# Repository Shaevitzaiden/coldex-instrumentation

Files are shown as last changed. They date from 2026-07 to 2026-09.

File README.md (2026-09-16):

# Pneumatic Control Dashboard

This revision keeps the fixed-grid dashboard and multi-device StreamHub
architecture while adding a central actuator registry shared by every
relay-driven control surface.

## Central actuator registry

`config/actuators.yaml` is the authoritative mapping from logical actuator IDs
to physical `device_id + relay_number` bindings. Pneumatic valve elements and
crusher controls store only `actuator_id`; the current physical binding is
resolved when a command is queued.

This prevents separate widgets from independently claiming the same relay and
means changing one actuator binding updates every command producer at once.
See `ACTUATOR_REGISTRY_GUIDE.md`.

## Device connectivity tile

`type: device_connectivity` provides a passive hardware-health table for every
device in `config/devices.yaml`. It reports role, connection state, configured
port/baud, latest telemetry age, observed frame rate, and detected sequence
gaps. It consumes existing `DataHub` messages and never opens or polls serial
ports itself. See `DEVICE_CONNECTIVITY_GUIDE.md`.

## Combined plot + numeric sensor tile

`type: sensor_plot_readout` combines a live one-axis plot with current-value
cards for multiple compatible sensors. Use `metadata.quantity` in
`config/sensors.yaml` to classify sensor channels. The Add Dashboard Panel
dialog exposes a Measurement Group selector and only permits sensors with the
same quantity and unit. See `SENSOR_PLOT_READOUT_GUIDE.md` and
`examples/sensor_plot_readout_dashboard_examples.yaml`.

## Generic numeric readout tile

`type: sensor_readout` displays arbitrary configured sensor values as live
numeric cards. Multiple readout tiles may coexist and may group mixed quantities
when that is useful for one subsystem. See `SENSOR_READOUT_GUIDE.md`.

## Crusher control tile

`type: crusher_control` adds four side-by-side Up/Down controls for relay-driven
pneumatic crushers. The tile references four logical actuator IDs from the
central registry, shares the existing controller DeviceManager worker, waits for
command results before confirming state, and can request startup retraction.
Relay uniqueness is enforced centrally by `ActuatorRegistry`, rather than by
widget-to-widget conflict checks. See `CRUSHER_CONTROL_GUIDE.md` and
`examples/crusher_control_dashboard_example.yaml`.

## Eight-column detachable dashboard

The default main window is now an 8-column by 3-row fixed grid:

- Pneumatic Valve Panel: 4 columns wide and 2 rows tall at upper left.
- Ice Crushers: 4 columns wide directly beneath the pneumatic panel.
- Live Sensor Plots: 2-column middle strip spanning the upper two rows.
- Sensor Values cards: 2-column middle strip on the bottom row.
- Session Recording: 2-column full-height right rail spanning all three rows.

The system log and device-connectivity tiles remain available, but are no longer
forced into the shipped main-window layout; they can be added into a free grid
location or spawned directly as floating windows.

Every dashboard tile can be opened as its own top-level window with the `↗`
button. Detached panels free their former grid cells for other widgets. The
window-manager **X** now closes/hides a floating panel instead of redocking it;
`↙` is the only redock action. Closed panels can be restored from **Dashboard →
Reopen Closed Panel…**. Saved layouts persist detached geometry and also persist
closed floating panels as `visible: false`.

For temporary or secondary panels, **Dashboard → Spawn Floating Panel…**
(`Ctrl+Shift+F`) creates the selected tile directly in a separate window, without
first placing it into the main grid. Multiple newly spawned windows are slightly
cascaded so they do not initially cover one another.

Session Recording has also been compacted for its narrow right rail: shortened
visible sensor labels, compact headers/path controls, and stretch behavior that
keeps the sensor-name column flexible while minimizing horizontal scrolling.

This custom mechanism deliberately keeps the stable fixed-grid dashboard instead
of using Qt's native dock splitter engine. See `DETACHABLE_DASHBOARD_GUIDE.md`.

### Recent usability changes

- Directly spawned floating panels no longer expand the main dashboard with a
  phantom bottom row. Empty docked rows collapse until a panel is redocked.
- The Ice Crushers panel has an always-visible **Configure Relay Bindings...**
  action for first-launch hardware setup. Bindings are validated globally and
  saved immediately to `config/actuators.yaml`.

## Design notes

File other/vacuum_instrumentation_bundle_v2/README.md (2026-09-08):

# Vacuum Instrumentation Integration Bundle v2

Reference code, wiring, and purchasing information for:
- Leybold GRAPHIX gauge controller via RS-232
- Granville-Phillips 475001-00-T via analog output
- MKS PDR-D-1 via analog DC output
- Adafruit Feather RP2040 Adalogger used directly as a low-cost four-channel USB analog DAQ

## What changed in v2
The external ADS1115 is now **optional**, not part of the baseline design. The Feather RP2040 Adalogger already exposes four onboard 12-bit ADC channels (A0-A3), which are adequate for these slow pressure-controller outputs when used with a resistor divider, RC filter, firmware averaging, and calibration.

The ADS1115 examples are retained as an upgrade path if later measurements need a more stable reference, better linearity/resolution, differential acquisition, or additional analog-performance margin.

## Recommended baseline hardware
One Feather RP2040 Adalogger acquires both analog instruments:
- A0 <- Granville-Phillips 475 analog output through 30.1k/10.0k divider
- A1 <- MKS PDR-D-1 DC OUT through 30.1k/10.0k divider
- A2/A3 <- spare 0-10 V channels

Each populated channel also gets 100 nF from the ADC node to signal ground.

The GRAPHIX remains a separate direct RS-232 connection to the laptop.

## Quick start
1. See `docs/WIRING.md` and build the native-ADC divider/filter front end.
2. Flash `firmware/adalogger_native_adc_arduino/adalogger_native_adc_arduino.ino` (recommended baseline). No ADS1115 library is needed.
3. Install Python dependencies: `pip install -r python/requirements.txt`.
4. Test GRAPHIX with `python/examples/graphix_smoketest.py`.
5. Set the DAQ COM port and PDR Baratron full-scale value in your application/example.
6. Calibrate the analog channels against a DMM if absolute voltage accuracy matters.

## BOM
- `bom/BOM.xlsx`: grouped, formatted BOM with separate sheets for the analog DAQ core, GP475, PDR-D-1, GRAPHIX RS-232, and optional upgrades.
- `bom/BOM.csv`: flat version with the same group labels and product URLs.

Prices are snapshots and will change. Cable lengths are installation dependent.

## Important configuration checks
- GRAPHIX: confirm RS-232 mode/baud and use a straight-through DB9 cable. Do not use TTL UART or a null-modem adapter/cable.
- GP475: confirm analog output is 1 V/decade, 0-7 V and preferably zero programmed offset.
- PDR-D-1: identify the attached Baratron and enter its actual full-scale range in software.
- Homemade DAQ: non-isolated. Check inter-instrument ground potential before tying signal grounds together.

## Firmware folders
- `firmware/adalogger_native_adc_arduino/` — recommended, no external ADC
- `firmware/adalogger_native_adc_circuitpython/` — same electrical design in CircuitPython
- `firmware/adalogger_ads1115_arduino/` — optional higher-performance ADC path
- `firmware/adalogger_ads1115_circuitpython/` — optional higher-performance ADC path

## Sources
See `docs/SOURCES.md` and the purchase URLs in the BOM.

## Scope
This is reference integration code, not a certified measurement or safety system. Confirm connector pinouts and instrument configuration against the exact hardware/manual before wiring.

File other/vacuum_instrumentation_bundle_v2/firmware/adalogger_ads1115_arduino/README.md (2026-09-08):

# Arduino firmware
Board: Adafruit Feather RP2040 Adalogger. Install the Adafruit RP2040 board package and **Adafruit ADS1X15** library. Connect the ADS1115 by STEMMA QT/Qwiic or SDA/SCL. Open the native USB serial port at 115200 baud.

Commands: `PING`, `INFO`, `READ`, `START`, `STOP`, `RATE <Hz>`. Output is newline-delimited JSON. `volts[]` are reconstructed **instrument-side** voltages using a 49.9k/10k divider.

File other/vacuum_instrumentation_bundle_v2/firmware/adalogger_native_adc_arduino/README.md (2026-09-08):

# Adalogger native-ADC firmware (recommended baseline)

This firmware uses the Feather RP2040 Adalogger's four onboard analog inputs A0-A3. No external ADC is required for the GP475 and PDR-D-1.

## Electrical front end per channel
- 30.1 kΩ ±0.1% from instrument output to ADC node
- 10.0 kΩ ±0.1% from ADC node to signal ground
- 100 nF X7R from ADC node to signal ground

The divider gain is 4.01, so 10 V at the instrument becomes about 2.494 V at the Feather. This leaves room for the GP475's ~10 V fault indication and prevents normal signals from approaching the 3.3 V ADC limit.

## Arduino setup
Select the Adafruit Feather RP2040 board/core as appropriate and upload `adalogger_native_adc_arduino.ino`. No extra ADC library is required.

## Calibration
The RP2040 ADC is adequate for these slow gauges but is not a precision metrology ADC. For better absolute voltage accuracy, apply at least a two-point calibration per channel using a reliable DMM and known input voltages. Edit `CAL_SCALE` and `CAL_OFFSET_V` in the sketch.

## USB commands
`PING`, `INFO`, `READ`, `START`, `STOP`, and `RATE <Hz>`.

The JSON sample format is intentionally identical to the ADS1115 firmware so the same Python host driver works with either implementation.

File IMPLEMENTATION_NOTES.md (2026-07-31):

# Implementation Notes — v6.8 Multi-Device Stream Hub

## Scope

The stable v6.7 fixed-grid GUI and valve editor were retained. The backend was refactored through migration phases 1–5:

1. source-qualified data models;
2. multiple independent device workers;
3. centralized thread-safe pub/sub;
4. recorder consumption and disk work moved to a background thread;
5. one live sensor tile may contain multiple plot axes.

## Phase 1: source-qualified frames

`SensorDefinition` now includes:

- `sensor_id`: globally qualified runtime ID;
- `source_device`;
- `source_channel`;
- label, unit, expected rate, and recording metadata.

`SensorFrame` now includes:

- `source_id`;
- `host_received_monotonic_ns`;
- global `elapsed_s` based on one application monotonic origin;
- host UTC time;
- device timestamp and sequence;
- values keyed by global sensor IDs.

The worker uses the sensor configuration to map local packet channels to global IDs. Unknown local channels receive a deterministic `<device_id>.<channel>` fallback.

## Phase 2: DeviceManager

The single `HardwareService` was replaced by:

- `DeviceManager`: lifecycle and command router;
- `SerialDeviceService`: queue/thread/worker owner for one device;
- `DeviceWorker`: communicator owner, packet parser boundary, and command executor.

Every enabled device receives one `QThread`. This isolates blocking instruments and guarantees one owner per serial port.

The old `HardwareService` and `HardwareWorker` import names remain aliases for migration compatibility, but new code should import `DeviceManager` and `DeviceWorker`.

`run_app()` accepts:

```python
communicators={"controller": controller, "flow_meter": meter}
```

The previous `communicator=controller` argument is still accepted and assigned to the configured command-target device.

## Phase 3: StreamHub

`StreamHub` has no Qt dependency. It provides:

- named topics;
- independent bounded subscriber queues;
- configurable overflow policy;
- latest-by-topic cache;
- latest value per sensor;
- latest frame per source;
- bounded per-sensor history;
- known-topic discovery.

Typed publishing helpers create topics for frames, per-channel samples, logs, command results, and device status.

`DataHub` is now only a GUI-thread cache and Qt signal facade. `QtDataBridge` drains StreamHub subscriptions on a timer and feeds DataHub. Full-rate consumers bypass that bridge.

## Phase 4: recorder worker

`SessionRecorder` is now a QObject facade around:

- a dedicated Python thread;
- frame and log StreamHub subscriptions;
- a recorder command queue;
- a pure `_RecorderState` file/persistence implementation.

Autosave and file writes occur in the recorder thread. Manual persistence commands first drain all frames/logs already queued before writing. Shutdown finalization blocks until the recorder confirms final files are complete.

The recorder uses a large bounded subscription. Overflow is logged as an error rather than allowing unbounded memory growth.

## Phase 5: multi-axis plotting

`LivePlotTile` accepts either:

- explicit `plot_groups`; or
- a flat channel list with `group_by_unit` enabled.

With pyqtgraph installed, a `GraphicsLayoutWidget` contains one `PlotItem` per group. Each channel has its own buffer/curve. Frames only append data; a 50 ms timer redraws the plots.

The fallback renderer creates one lightweight QWidget plot per group when pyqtgraph is unavailable.

## Thread ownership summary

```text
GUI thread
    MainWindow, ValvePanelCanvas, DataHub, QtDataBridge, plot widgets

One QThread per device
    communicator connect/read/write/disconnect, packet normalization

Recorder Python thread
    full-rate subscriptions, CSV/YAML writes, snapshots, autosave

Future automation threads
    direct StreamHub subscriptions and DeviceManager commands
```

## Tests performed

Because PyQt5 is not installed in the artifact environment, visual launch testing was not possible. The following checks were run:

- Python `compileall` across the complete project;
- device and sensor YAML loading;
- globally qualified local-channel normalization;
- multiple independent StreamHub subscriptions;
- latest-value and bounded-history queries;
- background recorder consumption from multiple source devices;
- separate per-sensor CSV creation and manifest finalization;
- archive content validation.

Minimal PyQt stubs were used only to load QObject-derived backend classes during non-visual tests; the actual project still depends on PyQt5 at runtime.

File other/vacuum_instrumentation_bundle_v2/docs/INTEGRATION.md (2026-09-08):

# Integration notes

## Recommended acquisition topology

- Leybold GRAPHIX -> USB-to-RS232 adapter -> laptop -> `GraphixController`
- GP475 -> divider/filter -> Feather A0
- PDR-D-1 -> divider/filter -> Feather A1
- Feather RP2040 Adalogger -> native USB CDC -> laptop -> `USBDaq`

Both native-ADC and optional ADS1115 firmware emit the same newline-delimited JSON sample format, so the Python host layer does not need to know which ADC implementation is installed.

## Why native ADC is the baseline
The pressure-controller outputs are slow, high-level analog signals. The Feather's four onboard RP2040 12-bit ADC channels provide enough practical resolution once the 0-10 V range is divided down. The external ADS1115 is therefore an accuracy/linearity/differential-input upgrade, not a functional requirement.

For the native implementation, use firmware averaging and calibrate gain/offset if measurement accuracy matters. Keep physical pressure conversion in Python so the DAQ firmware remains a generic voltage acquisition device.

## Data flow
Recommended host architecture:

`instrument driver/DAQ -> normalized Measurement -> DataHub -> GUI + logger + control logic`

Do not perform serial reads synchronously in the Qt GUI thread. Use a worker thread or asynchronous service and emit measurements/signals to the GUI.

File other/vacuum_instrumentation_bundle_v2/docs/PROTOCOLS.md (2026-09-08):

# Protocol summary

## Leybold GRAPHIX
Host is master. RS-232: ASCII messages, 8-N-1, no hardware handshake. Control bytes: SI=0x0F read, SO=0x0E write, ACK=0x06, NACK=0x15, EOT=0x04, separator `;`.

Read frame: `[SI]group;parameter CRC[EOT]`.
CRC byte = `255 - (sum(all preceding bytes) mod 256)`; if result < 32, add 32.
Read response: `[ACK]value CRC[EOT]` or `[NACK]error CRC[EOT]`.
Pressure channels are groups 1,2,3; parameter 29 is rounded/corrected pressure with unit. Group 5 parameter 1 is hardware/software version and is a useful communications smoke test.

## Adalogger USB DAQ
Included firmware uses newline-delimited JSON over native USB serial. Example:
`{"type":"sample","t_us":123456,"volts":[4.000001,5.000002,0.0,0.0]}`
Commands: PING, INFO, READ, START, STOP, RATE <0.2..25>.

## GP475 conversion
Default 0–7 V log mode: Torr or mbar: `P=10^(V-4)`; Pa: `P=10^(V-2)`. A 10 V output indicates unplugged/faulty gauge. Optional 1–8 V mode shifts exponent by -1. S-curve mode is intentionally not implemented in the Python helper.

## PDR-D-1 conversion
For a correctly configured 0–10 V full-scale Baratron readout: `P = (V/10) * P_full_scale`. Confirm the actual Baratron full-scale range/nameplate before logging engineering units.

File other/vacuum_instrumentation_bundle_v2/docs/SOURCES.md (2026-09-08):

# Sources and product references

## Instrument documentation
- Leybold GRAPHIX operating instructions: https://global.shop.leybold.com/medias/GA300550402-002-Instructions.pdf
- MKS Granville-Phillips 475 manual: https://api.p1.mks.com/medias/sys_master/resources/h8f/h64/9954649800734/GP-475Controller475101-MAN/GP-475Controller475101-MAN.pdf
- MKS PDR-D-1/PDR-D-2 manual mirror: https://clara.nz/docs/hardware-unsorted/mks/Pdr-d-man.pdf

## DAQ platform and ADC references
- Adafruit Feather RP2040 Adalogger: https://www.adafruit.com/product/5980
- Raspberry Pi RP2040 datasheet: https://datasheets.raspberrypi.com/rp2040/rp2040-datasheet.pdf
- Adafruit ADS1115 (optional upgrade): https://www.adafruit.com/product/1085
- TI ADS1115 datasheet: https://www.ti.com/lit/ds/symlink/ads1115.pdf

## Purchase links
The consolidated, grouped purchase links are in `../bom/BOM.xlsx` and `../bom/BOM.csv`.

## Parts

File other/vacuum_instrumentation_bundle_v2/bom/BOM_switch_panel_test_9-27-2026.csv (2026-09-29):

Quantity | Unit | Item | Manufacturer / Part | ~Unit Price | Purchase URL
1 | ea | Taiss 10pcs DPDT Mini Toggle Switch - 6-Pin 3 Position ON/Off/ON - 6A 125V MTS-203 | Taiss | 8.66 | https://www.amazon.com/mts-202-125VAC-Position-Toggle-Switch/dp/B0799JV8GN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
1 | ea | BOJACK 1000 Pcs 25 Values Resistor Kit 1 Ohm-1M Ohm with 5% 1/4W Carbon Film Resistors Assortment | BOJACK | 9.99 | https://www.amazon.com/BOJACK-Values-Resistor-Resistors-Assortment/dp/B08FD1XVL6
 |  |  |  | Total
 |  |  |  | 18.65

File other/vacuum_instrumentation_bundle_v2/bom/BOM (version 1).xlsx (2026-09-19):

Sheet: BOM
Group | Include | Qty Current Build | Qty If All 4 Analog Channels Populated | Unit | Item | Manufacturer / Part | Approx Unit Price USD | Use | Wiring / Placement | Purchase URL | Notes
Analog DAQ Core | Yes | 1 | 1 | ea | Adafruit Feather RP2040 Adalogger | Adafruit PID 5980 | 14.95 | USB DAQ controller; uses onboard A0-A3 12-bit ADCs | USB-C to laptop; A0=GP475, A1=PDR-D-1; GND is analog return | https://www.adafruit.com/product/5980 | External ADS1115 is not required for the baseline design.
Analog DAQ Core | Yes | 1 | 1 | ea | USB Type-A to USB-C data cable, ~1 m | Adafruit PID 4474 | 4.95 | DAQ-to-laptop USB data and power | Laptop USB-A <-> Feather USB-C | https://www.adafruit.com/product/4474 | Substitute a known data-capable USB-C cable if your laptop uses USB-C.
Analog DAQ Core | Yes | 1 | 1 | ea | Half-size Perma-Proto PCB | Adafruit PID 1609 | 4.5 | Mount resistor dividers, filters and terminal blocks | Solder front-end components; wire A0-A3 and GND to Feather | https://www.adafruit.com/product/1609 | A custom PCB can replace this later.
Analog DAQ Core | Yes | 2 | 4 | ea | 30.1 kÎ© Â±0.1% metal-film resistor | TE Connectivity YR1B30K1CC | 1.01 | Top resistor in each 0-10 V divider | Instrument signal -> 30.1k -> ADC node | https://www.digikey.com/en/products/detail/te-connectivity-passive-product/YR1B30K1CC/18101807 | One per populated analog channel.
Analog DAQ Core | Yes | 2 | 4 | ea | 10.0 kÎ© Â±0.1% metal-film resistor | TE Connectivity YR1B10KCC | 0.97 | Bottom resistor in each 0-10 V divider | ADC node -> 10.0k -> signal ground | https://www.digikey.com/en/products/detail/te-connectivity-passive-product/YR1B10KCC/2389737 | With 30.1k top resistor, divider reconstruction gain = 4.01.
Analog DAQ Core | Yes | 2 | 4 | ea | 100 nF, 50 V, X7R ceramic capacitor | Murata RDER71H104K0K1H03B | 0.52 | Low-pass/noise filter on each ADC input | ADC node -> 100 nF -> signal ground | https://www.digikey.com/en/products/detail/murata-electronics/RDER71H104K0K1H03B/4770969 | One per populated analog channel.
Analog DAQ Core | Yes | 2 | 4 | ea | 2-pin 2.54 mm screw terminal block | Adafruit PID 2138 | 0.95 | Detachable signal/ground input for each analog instrument | One terminal pair per analog channel | https://www.adafruit.com/product/2138 | 26-20 AWG rated by Adafruit.
Analog DAQ Core | If needed | 1 | 1 | set | 22 AWG solid-core hookup wire set | Adafruit PID 1311 | 15.95 | Internal DAQ wiring between Feather and protoboard | Short internal point-to-point runs only | https://www.adafruit.com/product/1311 | Use existing lab hookup wire instead if available; not included in baseline total.
GP475 Analog | Yes | 1 | 1 | ea | 3.5 mm plug to screw-terminal adapter | Adafruit PID 2790 | 2.5 | Break out the GP475 rear analog-output phone jack | Use the signal/return contacts specified by the GP475 manual; leave unused contact open | https://www.adafruit.com/product/2790 | This adapter is TRS; verify the exact GP475 jack contact assignment before wiring.
GP475 Analog | Yes | 6 | 6 | ft | Belden 9451 shielded twisted-pair cable | Belden 9451 (DigiKey cut length) | 1.61 | GP475 analog signal and return to DAQ | GP475 adapter -> shielded pair -> DAQ CH0 terminal | https://www.digikey.com/en/products/detail/belden-inc/9451-008500/28740168 | 6 ft is a budgeting assumption; order the actual installation length.
PDR-D-1 Analog | Yes | 6 | 6 | ft | Belden 9451 shielded twisted-pair cable | Belden 9451 (DigiKey cut length) | 1.61 | PDR-D-1 DC OUT and S GND to DAQ | PDR DC OUT -> signal conductor; S GND -> return -> DAQ CH1 terminal | https://www.digikey.com/en/products/detail/belden-inc/9451-008500/28740168 | 6 ft is a budgeting assumption; PDR side lands directly on the existing rear terminal strip.
GRAPHIX RS232 | Yes | 1 | 1 | ea | FTDI USB-to-RS232 adapter, DB9 male | USBGear USBG-232 | 21.29 | Convert laptop USB to true RS-232 for GRAPHIX | Laptop USB -> USBG-232 -> straight-through DB9 extension -> GRAPHIX | https://www.usbgear.com/usbg-232.html | Preferred robust option; FT231X and ESD protection. Do not substitute TTL UART.
GRAPHIX RS232 | Yes | 1 | 1 | ea | 1 m shielded straight-through DB9 male-to-female cable | StarTech MXT1001MBK | 9.21 | GRAPHIX serial extension | USB-RS232 adapter DB9 -> straight-through cable -> GRAPHIX DB9 | https://www.startech.com/en-us/cables/mxt1001mbk | Must be straight-through, not null modem.
Optional Upgrades | Optional | 1 | 1 | ea | ADS1115 16-bit ADC breakout | Adafruit PID 1085 | 14.95 | Optional higher-resolution/stability ADC | STEMMA QT/I2C to Feather; analog dividers then feed ADS1115 inputs | https://www.adafruit.com/product/1085 | Useful if later accuracy, differential acquisition or ADC linearity warrants it; not required now.
Optional Upgrades | Optional | 1 | 1 | ea | STEMMA QT / Qwiic 4-pin cable, 50 mm | Adafruit PID 4399 | 0.95 | Connect optional ADS1115 to Feather | Feather STEMMA QT <-> ADS1115 STEMMA QT | https://www.adafruit.com/product/4399 | Only needed with the ADS1115 upgrade.
Optional Upgrades | Budget alternative | 1 | 1 | ea | USB-to-RS232 adapter, DB9 male | Sabrent CB-9P6F | 11.99 | Lower-cost alternative to USBGear GRAPHIX adapter | Laptop USB -> adapter -> straight-through DB9 -> GRAPHIX | https://sabrent.com/products/cb-9p6f | Use instead of, not in addition to, the USBGear adapter.
Optional Upgrades | USB-C alternative | 1 | 1 | ea | USB-C to RS232 FTDI adapter, DB9 male | USBGear USBG-232-C | 26.49 | Direct USB-C alternative for GRAPHIX | Laptop USB-C -> adapter -> straight-through DB9 -> GRAPHIX | https://www.usbgear.com/usbg-232-c.html | Use instead of the USB-A USBGear adapter if preferred.
All | Optional | 1 | 1 | ea | Arduino Due | Arduino |  | Controll pneumatics, sample sensors |  | https://www.mouser.com/en/ProductDetail/Arduino/A000062?qs=D9UofrEmuWn3CLF7hFoZGA%3D%3D
 | Yes | 1 | 1 | ea | Power Supply | Mean well |  | Primary power supply |  | https://www.mouser.com/en/ProductDetail/MEAN-WELL/HDR-150-24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
 | Yes | 1 | 1 | ea | Small DIN Rail | Mean well |  | Mount din pwr supplies |  | https://www.mouser.com/en/ProductDetail/MEAN-WELL/TS35-75-200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
 | Yes | 1 | 1 | ea | 5V din regulator | Mean well |  | Power relay modules |  | https://www.mouser.com/en/ProductDetail/MEAN-WELL/DDR-15G-5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
 | Yes | 1 | 1 | ea | 12V din regulator | Mean well |  | Power main microcontroller |  | https://www.mouser.com/en/ProductDetail/MEAN-WELL/DDR-15G-12
 | Optional | 1 | 1 | ea | USB-C/A to USB-A hub | anker |  | Connect all serial usb devices |  | https://www.amazon.com/Anker-Transfer-Extended-Charging-Supported/dp/B0CCDZWH5H
 |  |  |  |  | Acrylic

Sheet: BOM_revised
Group | Include | Qty Current Build | Qty If All 4 Analog Channels Populated | Unit | Item | Manufacturer / Part | Approx Unit Price USD | Use | Wiring / Placement | Purchase URL | Alt Link | Notes
Analog DAQ Core | Yes | 1 | 1 | ea | Adafruit Feather RP2040 Adalogger | Adafruit PID 5980 | 14.95 | USB DAQ controller; uses onboard A0-A3 12-bit ADCs | USB-C to laptop; A0=GP475, A1=PDR-D-1; GND is analog return | https://www.adafruit.com/product/5980 |  | External ADS1115 is not required for the baseline design.
Analog DAQ Core | Yes | 1 | 1 | ea | USB Type-A to USB-C data cable, ~1 m | Adafruit PID 4474 | 4.95 | DAQ-to-laptop USB data and power | Laptop USB-A <-> Feather USB-C | https://www.adafruit.com/product/4474 |  | Substitute a known data-capable USB-C cable if your laptop uses USB-C.
Analog DAQ Core | Yes | 1 | 1 | ea | Half-size Perma-Proto PCB | Adafruit PID 1609 | 4.5 | Mount resistor dividers, filters and terminal blocks | Solder front-end components; wire A0-A3 and GND to Feather | https://www.adafruit.com/product/1609 |  | A custom PCB can replace this later.
Analog DAQ Core | Yes | 2 | 4 | ea | 30.1 kOhm ±0.1% metal-film resistor | TE Connectivity YR1B30K1CC | 1.01 | Top resistor in each 0-10 V divider | Instrument signal -> 30.1k -> ADC node | https://www.digikey.com/en/products/detail/te-connectivity-passive-product/YR1B30K1CC/18101807 | https://www.mouser.com/en/ProductDetail/TE-Connectivity-Holsworthy/YR1B30K1CC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 | One per populated analog channel.
Analog DAQ Core | Yes | 2 | 4 | ea | 10.0 kOhm ±0.1% metal-film resistor | TE Connectivity YR1B10KCC | 0.97 | Bottom resistor in each 0-10 V divider | ADC node -> 10.0k -> signal ground | https://www.digikey.com/en/products/detail/te-connectivity-passive-product/YR1B10KCC/2389737 | https://www.mouser.com/en/ProductDetail/TE-Connectivity-Holsworthy/YR1B10KCC?qs=VHcS2MTj4gZAHnFpyW81RQ%3D%3D | With 30.1k top resistor, divider reconstruction gain = 4.01.
Analog DAQ Core | Yes | 2 | 4 | ea | 100 nF, 50 V, X7R ceramic capacitor | Murata RDER71H104K0K1H03B | 0.52 | Low-pass/noise filter on each ADC input | ADC node -> 100 nF -> signal ground | https://www.digikey.com/en/products/detail/murata-electronics/RDER71H104K0K1H03B/4770969 | https://www.mouser.com/en/ProductDetail/Murata-Electronics/RDER71H104K0K1H03B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 | One per populated analog channel.
Analog DAQ Core | Yes | 2 | 4 | ea | 2-pin 2.54 mm screw terminal block | Adafruit PID 2138 | 0.95 | Detachable signal/ground input for each analog instrument | One terminal pair per analog channel | https://www.adafruit.com/product/2138 | https://www.mouser.com/en/ProductDetail/Amphenol-Anytek/VN02A1500000G?qs=Mv7BduZupUgf8d3Xo6xdxw%3D%3D | 26-20 AWG rated by Adafruit.
Analog DAQ Core | If needed | 1 | 1 | set | 22 AWG solid-core hookup wire set | Adafruit PID 1311 | 15.95 | Internal DAQ wiring between Feather and protoboard | Short internal point-to-point runs only | https://www.adafruit.com/product/1311 | https://www.amazon.com/dp/B07TX6BX47?lv=shuf&channelId=500&plpRedirect=mhFallback&th=1 | Use existing lab hookup wire instead if available; not included in baseline total.
GP475 Analog | Yes | 1 | 1 | ea | 3.5 mm plug to screw-terminal adapter | Adafruit PID 2790 | 2.5 | Break out the GP475 rear analog-output phone jack | Use the signal/return contacts specified by the GP475 manual; leave unused contact open | https://www.adafruit.com/product/2790 |  | This adapter is TRS; verify the exact GP475 jack contact assignment before wiring.
GP475 Analog | Yes | 6 | 6 | ft | Belden 9451 shielded twisted-pair cable | Belden 9451 (DigiKey cut length) | 1.61 | GP475 analog signal and return to DAQ | GP475 adapter -> shielded pair -> DAQ CH0 terminal | https://www.digikey.com/en/products/detail/belden-inc/9451-008500/28740168
PDR-D-1 Analog | Yes | 6 | 6 | ft | Belden 9451 shielded twisted-pair cable | Belden 9451 (DigiKey cut length) | 1.61 | PDR-D-1 DC OUT and S GND to DAQ | PDR DC OUT -> signal conductor; S GND -> return -> DAQ CH1 terminal | https://www.digikey.com/en/products/detail/belden-inc/9451-008500/28740168
GRAPHIX RS232 | Yes | 1 | 1 | ea | FTDI USB-to-RS232 adapter, DB9 male | USBGear USBG-232 | 21.29 | Convert laptop USB to true RS-232 for GRAPHIX | Laptop USB -> USBG-232 -> straight-through DB9 extension -> GRAPHIX | https://www.amazon.com/Adapter-Chipset%EF%BC%8CDB9-Serial-Converter-Windows/dp/B0759HSLP1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
Primary Controller | Optional | 1 | 1 | ea | Arduino Due | Arduino |  | Controll pneumatics, sample sensors |  | https://www.mouser.com/en/ProductDetail/Arduino/A000062?qs=D9UofrEmuWn3CLF7hFoZGA%3D%3D
Primary Controller | Yes | 1 | 1 | ea | 12V din regulator | Mean well |  | Power main microcontroller |  | https://www.mouser.com/en/ProductDetail/MEAN-WELL/DDR-15G-12
All | Yes | 1 | 1 | ea | Power Supply | Mean well |  | Primary power supply |  | https://www.mouser.com/en/ProductDetail/MEAN-WELL/HDR-150-24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
Relays | Yes | 1 | 1 | ea | 5V din regulator | Mean well |  | Power relay modules |  | https://www.mouser.com/en/ProductDetail/MEAN-WELL/DDR-15G-5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
All (serial devices) | Optional | 1 | 1 | ea | USB-C/A to USB-A hub | anker |  | Connect all serial usb devices |  | https://www.amazon.com/Anker-Transfer-Ultra-Slim-Charging-Supported/dp/B07L32B9C2
Mounting | Yes | 1 | 1 | ea | Small DIN Rail | Mean well |  | Mount din pwr supplies |  | https://www.mouser.com/en/ProductDetail/MEAN-WELL/TS35-75-200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
Mounting | Yes
Mounting |  |  |  |  | Acrylic
Mounting | yes | 4 | 4 | ft | T-Slotted Framing Single 4-Slot Rail, Silver, 30 mm Square, Hollow |  |  | t-slot mounting |  | https://www.mcmaster.com/5537T97-5537T739/
Mounting |  |  |  |  | T-Slotted Framing End-Feed Single Nut for 30 mm High Rail, M6 Thread Size |  |  | t-slot mounting |  | https://www.mcmaster.com/5537T67/
 |  |  |  |  | 18-8 Stainless Steel Low-Profile Socket Head Screws with Hex Drive, M6 x 1 mm Thread, 16 mm Long |  |  | t-slot mounting |  | https://www.mcmaster.com/92855A616/
Mounting | yes |  |  |  | Moisture-Resistant Cushioning Washer for 1/4" Screw Size, 0.257" ID, 0.5" OD |  |  |  |  | https://www.mcmaster.com/93650A145/
Mounting | Yes |  |  |  | Nyloc nuts | Mcmaster
Mounting | Yes
Mounting |  | 2 | 2 | ea (10 pack) | Moisture-Resistant Cushioning Washer for Number 4 Screw Size, 0.125" ID, 0.250" OD | Mcmaster | 8.6 | general acrylic mounting |  | https://www.mcmaster.com/93650A320/

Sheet: Sheet1
Nice to have items
80/20 handle for carrying
80/20 cable tie mounts

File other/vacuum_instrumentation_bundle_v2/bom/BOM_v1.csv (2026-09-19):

Group | Include | Qty Current Build | Qty If All 4 Analog Channels Populated | Unit | Item | Manufacturer / Part | Approx Unit Price USD | Use | Wiring / Placement | Purchase URL | Alt Link | Notes
Analog DAQ Core | Yes | 1 | 1 | ea | Adafruit Feather RP2040 Adalogger | Adafruit PID 5980 | 14.95 | USB DAQ controller; uses onboard A0-A3 12-bit ADCs | USB-C to laptop; A0=GP475, A1=PDR-D-1; GND is analog return | https://www.adafruit.com/product/5980 |  | External ADS1115 is not required for the baseline design.
Analog DAQ Core | Yes | 1 | 1 | ea | USB Type-A to USB-C data cable, ~1 m | Adafruit PID 4474 | 4.95 | DAQ-to-laptop USB data and power | Laptop USB-A <-> Feather USB-C | https://www.adafruit.com/product/4474 |  | Substitute a known data-capable USB-C cable if your laptop uses USB-C.
Analog DAQ Core | Yes | 1 | 1 | ea | Half-size Perma-Proto PCB | Adafruit PID 1609 | 4.5 | Mount resistor dividers, filters and terminal blocks | Solder front-end components; wire A0-A3 and GND to Feather | https://www.adafruit.com/product/1609 |  | A custom PCB can replace this later.
Analog DAQ Core | Yes | 2 | 4 | ea | 30.1 kOhm ±0.1% metal-film resistor | TE Connectivity YR1B30K1CC | 1.01 | Top resistor in each 0-10 V divider | Instrument signal -> 30.1k -> ADC node | https://www.digikey.com/en/products/detail/te-connectivity-passive-product/YR1B30K1CC/18101807 | https://www.mouser.com/en/ProductDetail/TE-Connectivity-Holsworthy/YR1B30K1CC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 | One per populated analog channel.
Analog DAQ Core | Yes | 2 | 4 | ea | 10.0 kOhm ±0.1% metal-film resistor | TE Connectivity YR1B10KCC | 0.97 | Bottom resistor in each 0-10 V divider | ADC node -> 10.0k -> signal ground | https://www.digikey.com/en/products/detail/te-connectivity-passive-product/YR1B10KCC/2389737 | https://www.mouser.com/en/ProductDetail/TE-Connectivity-Holsworthy/YR1B10KCC?qs=VHcS2MTj4gZAHnFpyW81RQ%3D%3D | With 30.1k top resistor, divider reconstruction gain = 4.01.
Analog DAQ Core | Yes | 2 | 4 | ea | 100 nF, 50 V, X7R ceramic capacitor | Murata RDER71H104K0K1H03B | 0.52 | Low-pass/noise filter on each ADC input | ADC node -> 100 nF -> signal ground | https://www.digikey.com/en/products/detail/murata-electronics/RDER71H104K0K1H03B/4770969 | https://www.mouser.com/en/ProductDetail/Murata-Electronics/RDER71H104K0K1H03B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 | One per populated analog channel.
Analog DAQ Core | Yes | 2 | 4 | ea | 2-pin 2.54 mm screw terminal block | Adafruit PID 2138 | 0.95 | Detachable signal/ground input for each analog instrument | One terminal pair per analog channel | https://www.adafruit.com/product/2138 | https://www.mouser.com/en/ProductDetail/Amphenol-Anytek/VN02A1500000G?qs=Mv7BduZupUgf8d3Xo6xdxw%3D%3D | 26-20 AWG rated by Adafruit.
Analog DAQ Core | If needed | 1 | 1 | set | 22 AWG solid-core hookup wire set | Adafruit PID 1311 | 15.95 | Internal DAQ wiring between Feather and protoboard | Short internal point-to-point runs only | https://www.adafruit.com/product/1311 | https://www.amazon.com/dp/B07TX6BX47?lv=shuf&channelId=500&plpRedirect=mhFallback&th=1 | Use existing lab hookup wire instead if available; not included in baseline total.
GP475 Analog | Yes | 1 | 1 | ea | 3.5 mm plug to screw-terminal adapter | Adafruit PID 2790 | 2.5 | Break out the GP475 rear analog-output phone jack | Use the signal/return contacts specified by the GP475 manual; leave unused contact open | https://www.adafruit.com/product/2790 |  | This adapter is TRS; verify the exact GP475 jack contact assignment before wiring.
GP475 Analog | Yes | 6 | 6 | ft | Belden 9451 shielded twisted-pair cable | Belden 9451 (DigiKey cut length) | 1.61 | GP475 analog signal and return to DAQ | GP475 adapter -> shielded pair -> DAQ CH0 terminal | https://www.digikey.com/en/products/detail/belden-inc/9451-008500/28740168
PDR-D-1 Analog | Yes | 6 | 6 | ft | Belden 9451 shielded twisted-pair cable | Belden 9451 (DigiKey cut length) | 1.61 | PDR-D-1 DC OUT and S GND to DAQ | PDR DC OUT -> signal conductor; S GND -> return -> DAQ CH1 terminal | https://www.digikey.com/en/products/detail/belden-inc/9451-008500/28740168
GRAPHIX RS232 | Yes | 1 | 1 | ea | FTDI USB-to-RS232 adapter, DB9 male | USBGear USBG-232 | 21.29 | Convert laptop USB to true RS-232 for GRAPHIX | Laptop USB -> USBG-232 -> straight-through DB9 extension -> GRAPHIX | https://www.amazon.com/Adapter-Chipset%EF%BC%8CDB9-Serial-Converter-Windows/dp/B0759HSLP1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
GRAPHIX RS232 | yes | 1 | 1 | ea | Straight Through DB9 RS232 Serial Cable | Startech | 9.84 | Graphix extension |  | https://www.amazon.com/StarTech-com-Black-Straight-Through-Serial/dp/B00A6GIUZA
USB | Yes | 1 | 1 | ea | USB extender (2-pack) |  | 16.99 | extend short usb hub cables to PC somewhere |  | https://www.amazon.com/AINOPE-Extension-MATERIAL-Transfer-Compatible/dp/B086SZYG46
Primary Controller | Yes | 1 | 1 | ea | Arduino Due | Arduino | 62.19 | Controll pneumatics, sample sensors |  | https://www.mouser.com/en/ProductDetail/Arduino/A000062?qs=D9UofrEmuWn3CLF7hFoZGA%3D%3D
Primary Controller | Yes | 1 | 1 | ea | 12V din regulator | Mean well | 20.5 | Power main microcontroller |  | https://www.mouser.com/en/ProductDetail/MEAN-WELL/DDR-15G-12
All | Yes | 1 | 1 | ea | Power Supply | Mean well | 36.15 | Primary power supply |  | https://www.mouser.com/en/ProductDetail/MEAN-WELL/HDR-150-24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
Relays | Yes | 1 | 1 | ea | 5V din regulator | Mean well | 20.5 | Power relay modules |  | https://www.mouser.com/en/ProductDetail/MEAN-WELL/DDR-15G-5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
All (serial devices) | Yes | 1 | 1 | ea | USB hub (2-pack) | anker | 19.97 | Connect all serial usb devices |  | https://www.amazon.com/dp/B0FXYCPM8R/ref=twister_B0D9W7N1WG?_encoding=UTF8&th=1 |  | One for adalogger and due, one for non-mcu serial devices
PWR | Yes | 1 | 1 | ea | PWR distribution block red | Pheonix connect | 2.57 | 5V distrubution |  | https://www.digikey.com/en/products/detail/phoenix-contact/3273202/7596988
PWR | Yes | 1 | 1 | ea | PWR distribution block blue | Pheonix connect | 2.57 | GND distribution |  | https://www.digikey.com/en/products/detail/phoenix-contact/3273200/7596985
Mounting | Yes | 2 | 2 | ea (200mm) | Small DIN Rail | Mean well | 0.75 | Mount din pwr supplies |  | https://www.mouser.com/en/ProductDetail/MEAN-WELL/TS35-75-200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
Mounting | Yes | 2 | 2 | ea | Acrylic | Simbalux | 19.95 | Bottom and top plates |  | https://www.amazon.com/SimbaLux-Plexiglass-Transparent-Protective-Projects/dp/B084T6SXJ6
Mounting | yes | 1 | 1 | ft | T-Slotted Framing Single 4-Slot Rail, Silver, 30 mm Square, Hollow |  | 23.86 | t-slot mounting |  | https://www.mcmaster.com/5537T97-5537T739/
Mounting | yes | 2 | 2 | ea (10-pack) | T-Slotted Framing End-Feed Single Nut for 30 mm High Rail, M6 Thread Size |  | 5.29 | t-slot mounting |  | https://www.mcmaster.com/5537T67/
Mounting | yes | 1 | 1 | ea (25-pack) | 18-8 Stainless Steel Low-Profile Socket Head Screws with Hex Drive, M6 x 1 mm Thread, 18 mm Long |  | 17.59 | t-slot mounting |  | https://www.mcmaster.com/92855A617/
Mounting | yes | 1 | 1 | ea (25-pack) | Moisture-Resistant Cushioning Washer for 1/4" Screw Size, 0.257" ID, 0.5" OD |  | 8.18 | Acrylic frame mounting |  | https://www.mcmaster.com/93650A145/
Mounting | yes | 3 | 3 | ea (10 pack) | Moisture-Resistant Cushioning Washer for Number 4 Screw Size, 0.125" ID, 0.250" OD | Mcmaster | 8.6 | Mount parts to acrylic backing |  | https://www.mcmaster.com/93650A320/
Mounting | yes | 1 | 1 | ea | High Speed PETG 3d printer filament | Amazon | 16.99 | Print any and all supporting structures, spacers, etc |  | https://www.amazon.com/SUNLU-High-Speed-Filament-1-75mm/dp/B0D9NF7CJF
Mounting | yes | 1 | 1 | ea (5-pack) | 18-8 Stainless Steel Low-Profile Socket Head Screws with Hex Drive, M6 x 1 mm Thread, 70 mm Long | Mcmaster | 9.63 | Plate to plate mounting bolts |  | https://www.mcmaster.com/92855A645/
Mounting | Yes | 1 | 1 | ea (100-pack) | Corrosion-Resistant 18-8 Stainless Steel Nylon-Insert Locknut | Mcmaster | 6.94 | Mount parts to acrylic backing |  | https://www.mcmaster.com/93625A100/
Mounting | Yes | 2 | 2 | ea (25-pack) | 18-8 Stainless Steel Low-Profile Socket Head Screws | Mcmaster | 4.13 | Mount parts to acrylic backing |  | https://www.mcmaster.com/92855A319/
 |  |  |  |  |  |  | 452.63

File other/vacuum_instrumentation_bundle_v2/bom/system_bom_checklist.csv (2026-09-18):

Subsystem | Category | Item | Qty | Priority | Status | Device / Interface | Purpose | Example Part | Product / Reference URL | Notes
Core control | Existing equipment | Main control laptop | 1 | Required | Have | System | Runs PyQt GUI, logger, device services, and possibly Agilent software |  |  | Confirm enough USB/Ethernet connectivity and power.
Core control | Existing equipment | USB dock / hub | 2 | Required | Need to Buy | System | Central edge-access connection point for USB peripherals |  |  | Prefer externally powered if many USB devices are connected.
Core control | Controller | Arduino Due | 1 | Required | Need to Buy | Pneumatics / GC sync | Main low-level controller for pneumatic valves, relays, other solenoids, and GC APG I/O | Arduino Due | https://store.arduino.cc/products/arduino-due | 7–12 V recommended external input; 3.3 V logic.
Core control | DAQ | Adafruit Feather RP2040 Adalogger | 1 | Required | Need to Buy | Analog instruments | Samples GP475 and PDR-D-1 analog outputs; two spare ADC channels remain | Adafruit PID 5980 | https://www.adafruit.com/product/5980 | Baseline uses onboard A0–A3 ADCs; ADS1115 optional.
Core control | Cable | USB data cable for Arduino Due | 1 | Required | Have / Verify | Arduino Due | Laptop ? Due programming/data |  |  | Match Due USB connector and dock port.
Core control | Cable | USB-C data cable for Feather | 1 | Required | Have / Verify | Feather DAQ | Laptop/dock ? Feather USB data + power |  |  | Must be data-capable.
Power | Main PSU | 24 V DC main power supply | 1 | Required | Need to Buy | 24 V bus | Feeds pneumatic valves, solenoids, and downstream DC/DC converters | Mean Well HDR-150-24 (example) | https://www.meanwell.com/webapp/product/search.aspx?prod=HDR-150 | Final wattage must be checked against all 24 V actuator loads.
Power | DC/DC | 24 V ? 12 V regulator for Arduino Due | 1 | Required | Need to Buy | Arduino Due | Feeds Due barrel jack / VIN from main 24 V bus | Pololu D24V22F9 | https://www.pololu.com/product/2861 | Compact option; 9 V is inside Due's recommended input range.
Power | DC/DC | 24 V ? 5 V DIN-rail regulator | 1 | Required | Need to Buy | Relay power | Dedicated 5 V supply for relay coils/peripherals | Mean Well DDR-15G-5 | https://www.meanwell.com/webapp/product/search.aspx?prod=DDR-15G | Keep relay coil current off Due 5 V rail.
Power | Distribution | 24 V DIN terminal blocks / distribution blocks | 1 | Required | Optional | 24 V bus | Distribute +24 V and 0 V to branch circuits |  |  | Quantity depends on number of branches.
Power | Protection | Branch fuse holders / fused terminal blocks | 1 | Required | Optional | 24 V bus | Separate fusing for pneumatics, Due converter, relay converter, other solenoids |  |  | Finalize ratings after current budget.
Power | Protection | Main DC fuse / breaker after PSU | 1 | Recommended | Optional | 24 V bus | Protects primary 24 V distribution wiring |  |  | Coordinate with PSU and conductor ampacity.
Power | Mains | Mains inlet / switch / fuse or protected power entry | 1 | Recommended | Optional | 24 V PSU | Safe AC mains connection to PSU |  |  | Use enclosed, strain-relieved, rated implementation.
Power | Grounding | DIN PE / chassis ground terminals | 1 | Recommended | Optional | System | Protective-earth bonding and organized grounding |  |  | Useful with metal DIN rail / PSU enclosure.
Power | AC distribution | Laboratory power strip / PDU for standalone instruments | 1 | Required | Have | External instruments | Powers standalone instruments and laptop as applicable |  |  | Check current rating and outlet count.
Pneumatics | Existing equipment | SMC / Orange Coast manifold with VQC1A01-51 valves | 1 | Required | Have | Pneumatics | Primary pneumatic valve manifold |  |  | 24 V valve power switched through relays/drivers.
Pneumatics | Existing equipment | 5 V relay module(s) | 1 | Required | Have | Pneumatics | Switches 24 V valve/solenoid circuits under Due control | Elegoo 4-channel 5 V relay module (existing) |  | Confirm relay channel count and JD-VCC/VCC arrangement.
Pneumatics | Actuator wiring | 24 V valve/solenoid hookup wire | 1 | Required | Have | Pneumatics | Power wiring from fused distribution through relays to valves |  |  | Gauge based on current and run length.
Pneumatics | Protection | Flyback / suppression for inductive loads | 1 | Recommended | Have | Pneumatics | Reduces solenoid switching transients |  |  | Depends on coil built-in suppression and relay topology.
Pneumatics | Other actuators | Other 24 V solenoids / crusher actuators | 1 | Required | Have | Pneumatics | Additional controlled actuators |  |  | Record each coil's rated current before finalizing PSU/fuses.
GRAPHIX | Existing instrument | Leybold GRAPHIX gauge controller | 1 | Required | Have | RS-232 | Digital pressure measurement |  | https://www.leybold.com/en-us/products/vacuum-measurement-and-control/vacuum-gauge-and-pump-controllers/graphix | Confirm exact model and baud rate.
GRAPHIX | Interface | USB ? true RS-232 adapter | 1 | Required | Need to Buy | GRAPHIX | Laptop USB ? GRAPHIX RS-232 | USBGear USBG-232 (FTDI) | https://www.usbgear.com/usbg-232.html | Do not substitute TTL UART.
GRAPHIX | Cable | Straight-through DB9 male?female serial cable | 1 | Required | Need to Buy | GRAPHIX | Connects RS-232 adapter to GRAPHIX rear DB9 | StarTech MXT1001MBK or equivalent | https://www.startech.com/en-us/cables/mxt1001mbk | Must be straight-through, not null-modem.
GP475 | Existing instrument | Granville-Phillips / MKS 475 Convectron controller | 1 | Required | Have | Analog | Pressure measurement |  | https://www.mks.com/f/475-convectron-vacuum-gauge-controller | 475001-00-T uses analog output.
GP475 | Connector | 3.5 mm / 1?8 in analog-output breakout | 1 | Required | Need to Buy | GP475 | Breaks rear analog phone jack out to field wiring | 3.5 mm plug-to-terminal adapter | https://www.adafruit.com/product/2790 | Verify exact jack contact assignment against manual.
GP475 | Cable | Shielded twisted-pair analog cable | 1 | Required | Need to Buy | GP475 | Analog signal + return to DAQ | Belden 9451 or equivalent | https://www.digikey.com/en/products/detail/belden-inc/9451-008500/28740168 | Route away from solenoid wiring.
GP475 | Analog front end | 30.1 k? 0.1% divider resistor | 1 | Required | Need to Buy | DAQ CH0 | Top resistor for input divider |  |  | One per populated analog channel.
GP475 | Analog front end | 10.0 k? 0.1% divider resistor | 1 | Required | Need to Buy | DAQ CH0 | Bottom resistor for input divider |  |  | One per populated analog channel.
GP475 | Analog front end | 100 nF capacitor | 1 | Required | Need to Buy | DAQ CH0 | Input low-pass filtering |  |  | One per populated analog channel.
PDR-D-1 | Existing instrument | MKS PDR-D-1 readout / Baratron power supply | 1 | Required | Have | Analog | Pressure measurement |  | https://clara.nz/docs/hardware-unsorted/mks/Pdr-d-man.pdf | DC OUT referenced to S GND.
PDR-D-1 | Existing instrument | Attached MKS Baratron transducer | 1 | Required | Have | PDR-D-1 | Actual pressure sensor |  |  | Record exact model and full-scale pressure.
PDR-D-1 | Cable | Shielded twisted-pair analog cable | 1 | Required | Need to Buy | PDR-D-1 | DC OUT + S GND to DAQ | Belden 9451 or equivalent | https://www.digikey.com/en/products/detail/belden-inc/9451-008500/28740168 | Order actual run length.
PDR-D-1 | Analog front end | 30.1 k? 0.1% divider resistor | 1 | Required | Need to Buy | DAQ CH1 | Top resistor for input divider |  |  | One per channel.
PDR-D-1 | Analog front end | 10.0 k? 0.1% divider resistor | 1 | Required | Need to Buy | DAQ CH1 | Bottom resistor for ADC divider |  |  | One per channel.
PDR-D-1 | Analog front end | 100 nF capacitor | 1 | Required | Need to Buy | DAQ CH1 | Input low-pass filtering |  |  | One per channel.
LAUDA | Existing instrument | LAUDA RP 290 E NTRL | 1 | Required | Have | Ethernet | Temperature control, monitoring, pump control, status/alarm access |  | https://www.lauda.de/us/products/constant-temperature-equipment/thermostats/circulation-and-process-thermostats/pro | Serial S230000611; use Ethernet process interface.
LAUDA | Network | Ethernet patch cable | 1 | Required | Have / Verify | LAUDA | LAUDA ? switch/dock/laptop |  |  | Cat5e/Cat6 is sufficient.
Agilent 7890A | Existing instrument | Agilent Technologies 7890A GC | 1 | Required | Have | Ethernet + APG Remote | Gas chromatography; vendor software remains primary controller |  | https://www.agilent.com/ | Keep authoritative chromatogram acquisition in Agilent software.
Agilent 7890A | Network | Ethernet patch cable | 1 | Required | Have / Verify | 7890A | GC ? network for OpenLab/ChemStation |  |  | Cat5e/Cat6.
Agilent 7890A | Sync interface | DB9 cable / breakout for APG REMOTE | 1 | Required | Have / Verify | 7890A ? Due | Carries READY/START/STOP/PREPARE synchronization |  |  | Wire only documented APG pins.
Agilent 7890A | Sync interface | Protected / optoisolated digital interface board | 1 | Recommended | TBD | 7890A ? Due | Buffers/protects APG signals between GC and Due |  |  | Final circuit/part selection still needs design.
Agilent 7890A | Optional analog | Shielded analog cable for SIG1/SIG2 | 1 | Optional | Optional | 7890A ? Feather | Live approximate detector trace in main GUI | Belden 9451 or equivalent | https://www.digikey.com/en/products/detail/belden-inc/9451-008500/28740168 | Not a replacement for native Agilent acquisition.
Network | Infrastructure | Small Ethernet switch | 1 | Conditional | Verify | LAUDA + 7890A + laptop | Provides enough wired network ports if dock/router does not |  |  | Needed only if existing network cannot accommodate both instruments.
Network | Infrastructure | Additional Ethernet patch cable to laptop/switch uplink | 1 | Conditional | Verify | Network | Completes network topology |  |  | Depends on final topology.
Mechanical | Structure | Rear mounting plate (acrylic or polycarbonate) | 1 | Required | Need to Buy | Assembly | Structural mounting surface |  |  | Polycarbonate is more tolerant of drilled/bolted mounting.
Mechanical | Structure | Front/top clear plate | 1 | Required | Need to Buy | Assembly | Protective cover / second plate |  |  | Material and thickness TBD.
Mechanical | Structure | Plate-to-plate standoffs/spacers | 1 | Required | Need to Buy | Assembly | Separates two sheets |  |  | Length depends on tallest component.
Mechanical | PCB mounting | M2.5/M3 PCB standoff assortment | 1 | Required | Need to Buy | Due / Feather / small boards | Mounts electronics above rear plate |  |  | Match board hole sizes.
Mechanical | General mounting | M3 machine bolts + washers + nyloc nuts | 1 | Required | Need to Buy | Small brackets / cable hardware | General through-bolted mounting |  |  | Use washers against plate.
Mechanical | Heavy mounting | M4 machine bolts + washers + nyloc nuts | 1 | Required | Need to Buy | DIN rail / cable bases / PSU | Structural through-bolted mounting |  |  | Good general standard for rear plate.
Mechanical | DIN rail | 35 mm DIN rail | 1 | Recommended | Need to Buy | Power/distribution | Mounts PSU, converters, fuses, terminals |  |  | Length based on final layout.
Cable management | Permanent routing | M4 bolt-mount cable-tie bases | 10 | Required | Optional | Internal cables | Fixes cable ties to rear plate | Panduit TM2S8-C | https://www.digikey.com/en/products/detail/panduit-corp/TM2S8-C/1306625 | Use M4 through-bolts, washer and nyloc nut.
Cable management | Reusable strain relief | Reusable ratchet cable clamp near USB dock | 1 | Recommended | Optional | USB dock | Protects dock-connected cable bundle from yanks | HellermannTyton RCA90SM6 / 151-01643 | https://www.hellermanntyton.com/products/clips-clamps-and-plugs/rca90sm6/151-01643 | Fits ~6.2–13.7 mm bundle; M6 mounting.
Cable management | Routing | Slotted wiring duct | 1 | Recommended | Optional | Assembly | Organizes longer cable runs |  |  | Prefer separate signal/analog and power ducts.
Cable management | Ties | Cable ties | 1 | Required | Have | Internal cables | Works with TM2S8-C bases |  |  | Choose widths compatible with bases.
Cable management | Reusable ties | Hook-and-loop cable straps | 1 | Recommended | Optional | Service loops | Reusable bundle restraint |  |  | Good near serviceable connections.
Cable management | Termination | Wire ferrules + ferrule crimper | 1 | Recommended | Optional | DIN terminal wiring | Reliable stranded-wire terminations |  |  | Useful for 24 V distribution and converters.
Cable management | Labeling | Wire / cable labels | 1 | Recommended | Have | All wiring | Identifies both ends of removable cables |  |  | Strongly recommended.
Optional upgrades | ADC | ADS1115 16-bit ADC breakout | 1 | Optional | Optional | Analog DAQ | Higher-resolution/differential alternative to Feather ADC | Adafruit PID 1085 | https://www.adafruit.com/product/1085 | Not required for baseline pressure acquisition.
Optional upgrades | Local logging | microSD card | 1 | Optional | Optional | Feather Adalogger | Local backup data logging |  |  | Feather already has microSD socket.

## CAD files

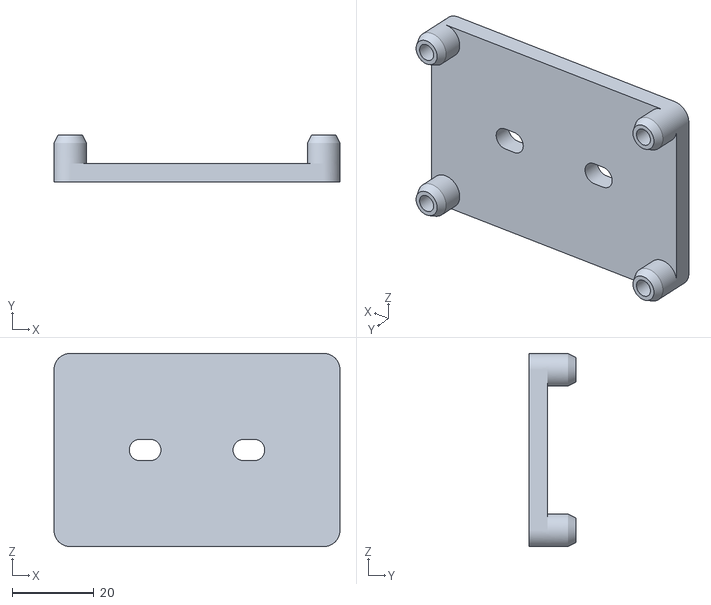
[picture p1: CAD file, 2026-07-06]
3d_models/mounting_hardware/t-slot_mount_2inx1inx12in/stl/proto-board_standoffs_plate_t-slot-2inx1in.stl
70.0 x 11.5 x 47.3

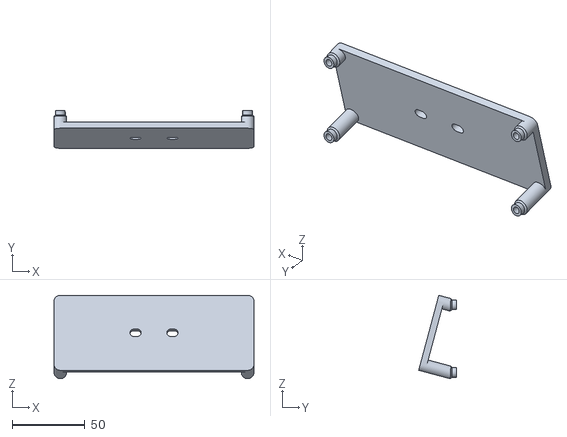
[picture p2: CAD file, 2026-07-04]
3d_models/mounting_hardware/t-slot_mount_2inx1inx12in/stl/relay_module_standoffs_angled_plate_t-slot-2inx1in.stl
137.7 x 25.9 x 57.4

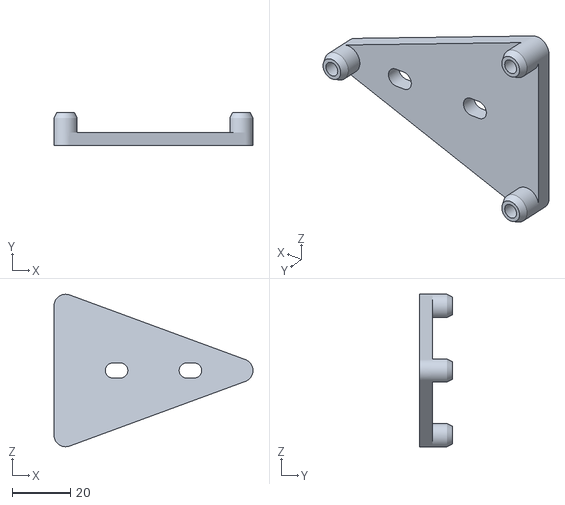
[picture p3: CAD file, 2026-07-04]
3d_models/mounting_hardware/t-slot_mount_2inx1inx12in/stl/db-25_standoffs_plate_t-slot-2inx1in.stl
68.5 x 11.5 x 52.5

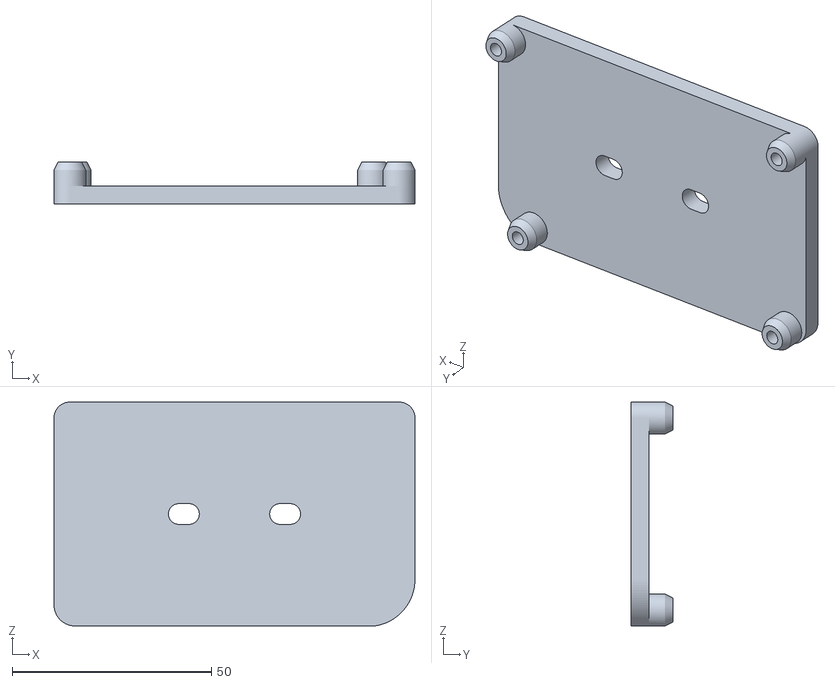
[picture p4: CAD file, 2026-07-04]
3d_models/mounting_hardware/t-slot_mount_2inx1inx12in/stl/arduino_mega_standoffs_plate_t-slot-2inx1in.stl
90.6 x 10.5 x 56.2

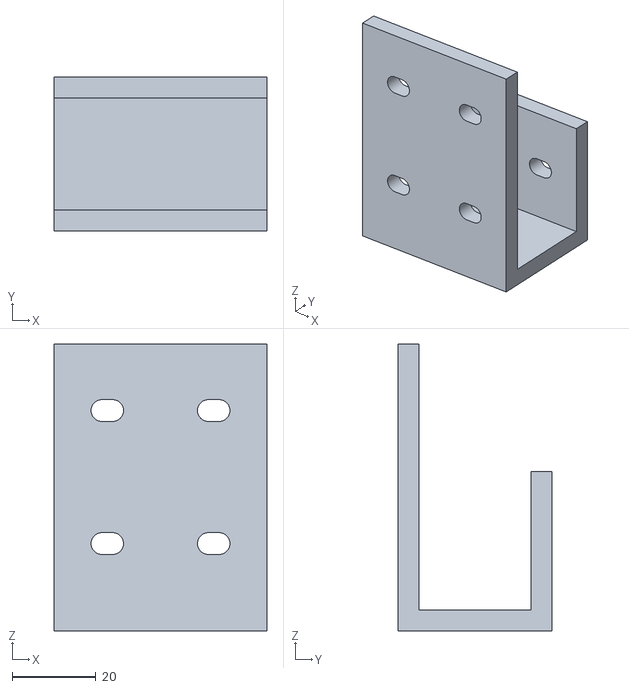
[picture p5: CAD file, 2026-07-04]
3d_models/mounting_hardware/t-slot_mount_2inx1inx12in/stl/hanging_bracket_t-slot-2inx1in.stl
50.8 x 36.8 x 68.5

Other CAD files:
3d_models/mounting_hardware/gcode/db-25-standoff_mega-clip.gcode.3mf
3d_models/mounting_hardware/McMaster/0.125in_innerD_Moisture-Resistant Cushioning Washer.ipt
3d_models/mounting_hardware/McMaster/0.257in_innerD_Moisture-Resistant Cushioning Washer.ipt
3d_models/mounting_hardware/McMaster/1ft_T-Slotted Framing.ipt
3d_models/mounting_hardware/McMaster/30mm_1ft_T-Slotted Framing.ipt
3d_models/mounting_hardware/McMaster/30mm_4ft_T-Slotted Framing.ipt
3d_models/mounting_hardware/McMaster/30mm_teenut_T-Slotted Framing.ipt
3d_models/mounting_hardware/McMaster/4ft_T-Slotted Framing.ipt
3d_models/mounting_hardware/McMaster/OldVersions/0.257in_innerD_Moisture-Resistant Cushioning Washer.0001.ipt
3d_models/mounting_hardware/McMaster/m6_16mm_18-8 Stainless Steel Low-Profile Socket Head Screws.ipt
3d_models/mounting_hardware/McMaster/m6_18mm_18-8 Stainless Steel Low-Profile Socket Head Screws.ipt
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

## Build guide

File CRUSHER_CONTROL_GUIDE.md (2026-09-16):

# Crusher Control Dashboard Tile

The `crusher_control` tile controls four relay-driven pneumatic crushers through
the same `DeviceManager` and controller worker used by the pneumatic valve
panel. It does **not** open another serial connection.

## Physical state convention

The crusher hardware is extended when its solenoid is unpowered and retracts
when the solenoid is powered:

- **Up arrow (▲)** -> relay ON -> solenoid powered -> crusher raised/retracted
- **Down arrow (▼)** -> relay OFF -> solenoid unpowered -> crusher lowered/extended

By default `initialize_retracted: true`, so the tile queues an ON command for
each configured crusher when the application starts. Set it to `false` if you
do not want startup actuation.

## Dashboard YAML

```yaml
- id: crushers_main
  type: crusher_control
  title: Ice Crushers
  row: 2
  column: 0
  row_span: 1
  column_span: 2
  removable: true
  config:
    device_id: controller
    initialize_retracted: true
    crushers:
      - id: crusher_1
        label: Crusher 1
        relay_number: 17
      - id: crusher_2
        label: Crusher 2
        relay_number: 18
      - id: crusher_3
        label: Crusher 3
        relay_number: 19
      - id: crusher_4
        label: Crusher 4
        relay_number: 20
```

The relay numbers above are examples only. Use the physical relay assignments
for your hardware.

## Relay conflict handling

The tile checks its relay assignments against the current pneumatic valve-panel
configuration. If a crusher relay is also assigned to a valve-panel element,
that crusher's buttons are disabled and a warning is shown. Duplicate relay
assignments within the crusher tile are also disabled.

The Add/Configure Dashboard Panel dialog requires four unique relay numbers from
1 through 24. YAML-loaded invalid configurations are handled defensively at
runtime rather than sending commands.

## Command path

A button press follows this path:

```
CrusherControlTile
    -> DeviceManager.set_element_state(...)
    -> SerialDeviceService command queue
    -> controller DeviceWorker
    -> communicator.set_element_state(...)
    -> physical relay
```

The tile then waits for the worker's `CommandResult`, delivered through
`QtDataBridge -> DataHub.relay_result_received`, before marking the new state as
confirmed. This keeps GUI state changes asynchronous and prevents the widget
from touching the serial port directly.

## Shared controller

`device_id: controller` selects the same device service that the pneumatic valve
panel uses. Both widgets therefore serialize commands through the same command
queue and the same communicator-owning worker thread.

## First-launch relay binding

The crusher panel now contains an always-available **Configure Relay Bindings...**
button.  It opens a focused editor for the four crusher actuators without
requiring Dashboard Edit Mode or removing/recreating the panel.  The editor
writes device/relay assignments to the central `config/actuators.yaml` registry,
validates all four assignments atomically against every other actuator (including
pneumatic valves), and saves the registry immediately.  The existing crusher
panel refreshes as soon as the bindings change.

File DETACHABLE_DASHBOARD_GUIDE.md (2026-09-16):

# Detachable dashboard panels

The operational dashboard remains a deterministic `QGridLayout`. It does **not**
return to Qt's native `QDockWidget` splitter system.

Every `TileWidget` has a `↗` button in its title bar:

- `↗` removes the tile from the grid and reparents the **same widget instance**
  into an ordinary top-level `DetachedTileWindow`.
- `↙` returns it to the main dashboard.
- Closing a detached window with the normal OS **X** closes/hides that panel; it does **not** redock it.
- `↙` is the only action that returns a floating panel to the main dashboard.
- Closed floating panels can be restored with **Dashboard → Reopen Closed Panel…**.

Because a floating tile is not counted when `DashboardWidget` checks occupied
cells, another panel may be placed in the cells it vacated. If the detached
panel is later returned and those cells are occupied, the dashboard searches for
the next free location with the same row/column span. It grows the grid when
necessary rather than overlap another panel.

## Spawn a panel directly as a window

Use **Dashboard → Spawn Floating Panel…** or `Ctrl+Shift+F`. This opens the same
configuration dialog used by Add Dashboard Panel, but the resulting tile is
created with `floating: true` immediately. No dashboard-edit-mode or temporary
grid placement is required.

Its stored row/column are merely the preferred location if it is later redocked.
New floating windows are slightly cascaded so several spawned panels do not open
exactly on top of one another.

## Persistence

`DashboardTileConfig` supports:

```yaml
floating: true
visible: false   # present when a floating panel has been closed/hidden
floating_geometry: [x, y, width, height]
```

A panel closed with the window-manager X keeps its configuration and last
floating geometry but does not occupy grid cells or create a top-level window.
Saving the dashboard preserves `visible: false`; use **Reopen Closed Panel…** to
make it visible again.

`DashboardWidget.current_config()` captures the geometry of every floating
window. Moving or resizing a detached window marks the dashboard dirty, so
**Save Dashboard Layout** persists its current location. On the next launch,
tiles saved with `floating: true` are recreated directly as separate windows.

If the saved monitor arrangement is unavailable, the window is placed near the
main application instead of restoring completely off-screen.

## Default 8-column × 3-row layout

```text
columns:   0   1   2   3 | 4   5 | 6   7
          +---------------+-------+-------+
row 0     |               |       |       |
          |  Pneumatic    | Live  |Session|
row 1     |  Valve Panel  | Plots |Record.|
          |               |       |       |
          +---------------+-------+       |
row 2     | Ice Crushers  |Sensor |       |
          |               |Cards  |       |
          +---------------+-------+-------+
```

- Pneumatic Valve Panel: `(row=0, column=0, row_span=2, column_span=4)`
- Ice Crushers: `(2, 0, 1, 4)`
- Live Sensor Plots: `(0, 4, 2, 2)`
- Sensor Values: `(2, 4, 1, 2)`
- Session Recording: `(0, 6, 3, 2)`

The terminal log, device connectivity, extra plots, and other tiles can be added
to new grid rows or spawned directly as separate windows.

## Floating panels no longer create empty dashboard rows

Panels created with **Dashboard -> Spawn Floating Panel...** keep a preferred
redock row/column, but those coordinates do not expand the live main-window
grid until the panel is actually redocked.  Likewise, when the last docked
panel leaves a row, that row's stretch becomes zero so it does not leave dead
space at the bottom of the dashboard.  The logical row count is still retained
in `dashboard.yaml` for later redocking/layout editing.

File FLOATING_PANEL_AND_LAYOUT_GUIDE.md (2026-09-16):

# 8-column equipment layout and direct floating panels

This revision changes only dashboard presentation/launch behavior; StreamHub,
DeviceManager, actuator routing, recording, sensor tiles, and command workers
remain unchanged.

## Main layout

The shipped dashboard is 8 columns × 3 rows. Pneumatics occupy 4×2, crushers are
4×1 underneath, the middle two columns are sensor visualization space, and the
right two columns are Session Recording across all three rows.

## Direct floating creation

`MainWindow._spawn_floating_dashboard_tile()` uses `TileConfigDialog`, then sets
`DashboardTileConfig.floating = True` before calling `DashboardWidget.add_tile`.
The normal `DashboardWidget._float_tile()` path therefore creates the same
`DetachedTileWindow` used when a docked panel's `↗` button is pressed.

This means a directly spawned window has the same persistence semantics as a
manually detached tile:

- it participates in `dashboard.yaml`;
- its geometry is saved;
- it is restored as a top-level window on launch;
- it can be redocked later;
- it consumes no grid cells while floating.

Shortcut: `Ctrl+Shift+F`.

## Compact recording rail

`RecordingPanel` keeps the same controls and functionality, but now uses a
compact browse toolbutton, shorter labels, shortened visible sensor names, and
header resize modes that reserve width for the sensor-name column. Full sensor
IDs and source information remain in tooltips.

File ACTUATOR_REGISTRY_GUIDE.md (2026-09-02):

# Central Actuator Registry

`config/actuators.yaml` is the authoritative mapping from a logical actuator
name to a physical hardware output.  New GUI and automation code should never
own a relay number independently.

```text
Pneumatic element -----\
                        -> actuator_id -> ActuatorRegistry -> device + relay
Crusher control -------/                        |
                                                 -> DeviceManager -> device worker
Future automation -----/
```

## Definition schema

```yaml
actuators:
  valve_01:
    label: Inlet Valve
    kind: solenoid_2_way
    device_id: controller
    relay_number: 1
    enabled: true
    default_active: false
```

Important fields:

- `actuator_id`: YAML key and stable global logical name.
- `device_id`: an entry from `config/devices.yaml`.
- `relay_number`: physical output on that device.
- `kind`: semantic type used for diagnostics/logging.
- `enabled`: disabled placeholders may remain unbound without validation errors.
- `default_active`: descriptive startup/default state for higher-level logic.
- `metadata`: actuator-specific semantic information.

The registry validates edited bindings against configured device IDs, relay
range, and every other actuator.  Relay swaps/multi-actuator edits are applied
atomically, so a rejected edit cannot leave a half-created registry entry.

## Pneumatic panel binding

`config/valve_panel.yaml` now contains:

```yaml
- id: valve_01
  actuator_id: valve_01
  ...
```

It does **not** contain a relay number. In valve-layout edit mode, both the
Add/Edit Element dialog and the Properties panel edit the referenced actuator's
Device and Relay fields in the central registry.  The canvas annotation resolves
and shows the live registry binding dynamically.

Changing a binding therefore affects every subsequent command immediately; the
pneumatic widget does not need to be rebuilt.

## Crusher binding

Crusher dashboard configuration also stores only logical IDs:

```yaml
crushers:
  - id: crusher_1
    label: Crusher 1
    actuator_id: crusher_1
```

The Crusher Controls configuration dialog edits the corresponding central
registry definitions.  Crusher and valve relay assignments are validated in the
same operation, so they cannot silently claim the same physical output.

## Global validation

The valve editor's **Validation / Relay Browser** now contains an **Actuator
Registry** tab showing every configured device/relay and its logical owner.
Validation reports:

- duplicate physical bindings;
- out-of-range relay numbers;
- enabled actuators with no relay;
- actuator definitions referencing unknown devices;
- pneumatic elements referencing missing actuator IDs;
- multiple pneumatic elements referencing the same logical actuator.

## Persistence and dirty state

Actuator edits have their own dirty state.  **Save Valve Layout** and **Save
Dashboard Layout** both persist `config/actuators.yaml` when necessary.  Closing
or loading another layout prompts for unsaved valve/actuator changes.

## Backward compatibility

Older `valve_panel.yaml` files containing `relay_number` and older crusher
dashboard configs containing `device_id`/`relay_number` are migrated in memory
at load time.  The next save writes the new actuator-ID schema and
`actuators.yaml`.  Historical conflicts are preserved during migration so the
validation UI can explain them instead of silently choosing a different relay.

## Command API

New widgets and automation should prefer:

```python
device_manager.set_actuator_state(
    actuator_id="valve_01",
    is_active=True,
    metadata={"origin": "automation.example"},
)
```

`DeviceManager` resolves the current registry binding immediately before the
command is queued.  Do not pass physical relays from new application code.
`set_element_state()` remains only as a lower-level/backward-compatible API for
external integrations and the final communicator boundary.

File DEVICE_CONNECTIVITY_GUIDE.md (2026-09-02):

# Device Connectivity Dashboard Tile

The `device_connectivity` tile is a GUI-only diagnostic consumer. It does not
open, close, or poll serial ports; `DeviceManager` remains the exclusive owner
of hardware lifecycle and serial I/O.

Add it through **Edit Dashboard Layout -> Add Dashboard Panel -> Device
connectivity**, or with YAML:

```yaml
- id: device_connectivity
  type: device_connectivity
  title: Device Connectivity
  row: 2
  column: 0
  row_span: 1
  column_span: 2
  removable: true
  config: {}
```

For every device in `config/devices.yaml`, the table displays:

- device ID and role (command target vs peripheral/data device);
- connected/disconnected/disabled state from `DeviceStatus`;
- configured serial port;
- configured baud rate;
- age of the most recent normalized sensor frame;
- GUI-observed frame rate over a rolling window;
- detected positive sequence-number gaps.

The data path is:

```text
DeviceWorker
   -> StreamHub devices/status/* and frames/*
   -> QtDataBridge
   -> DataHub
   -> DeviceConnectivityTile
```

A device may legitimately show `Connected` and `No data` if it is command-only
or does not publish sensor frames.

## Optional YAML configuration

The normal dialog displays every configured device. Advanced YAML may restrict
the table or change the frame-rate window:

```yaml
config:
  devices:
    - controller
    - thermocouple_board
  rate_window_s: 10
```

`rate_window_s` is only a GUI diagnostic window. Full-rate recording and future
automation still consume `StreamHub` directly.

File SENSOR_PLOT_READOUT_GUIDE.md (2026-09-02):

# Combined live plot + current-value tile

The dashboard now supports a reusable tile type:

```yaml
type: sensor_plot_readout
```

It is intended for several comparable sensor channels that should share one
live y-axis while also showing their current values as large text above the
plot. Typical examples are multiple temperatures, multiple pressures, or
multiple strain channels.

## Why channels must be one measurement group

One `sensor_plot_readout` tile has one y-axis. The selected sensors must
therefore have the same physical quantity **and the same unit**. For example:

- `controller.temperature` and `environment.temperature` in °C: valid.
- two pressure channels in kPa: valid.
- temperature + pressure: rejected.
- °C + °F: rejected until a unit-conversion layer is added.

The preferred way to classify sensors is in `config/sensors.yaml`:

```yaml
controller.temperature:
  label: Controller Temperature
  source_device: controller
  source_channel: controller_temperature
  unit: °C
  metadata:
    quantity: temperature
```

Known units are also recognized as a backwards-compatible fallback, but
`metadata.quantity` is clearer and scales to project-specific sensor types.

## Example dashboard tile

```yaml
- id: temperatures_with_plot
  type: sensor_plot_readout
  title: Temperatures
  row: 2
  column: 0
  row_span: 1
  column_span: 2
  removable: true
  config:
    channels:
      - controller.temperature
      - environment.temperature
    quantity: temperature
    unit: °C
    y_label: Temperature
    history_seconds: 60
    readout_columns: 2
    default_decimals: 1
    value_font_size: 20
    show_units: true
    show_source: true
    stale_after_s: 5
```

The `quantity`, `unit`, and `y_label` fields are written by the configuration
dialog for clarity. The tile still defensively validates the actual channel
definitions when it is constructed, so manually edited YAML cannot silently
combine incompatible curves.

## Per-sensor text formatting

As with `sensor_readout`, optional display overrides can be supplied:

```yaml
    display:
      controller.temperature:
        label: Controller
        decimals: 1
      environment.temperature:
        label: Room
        format: .2f
```

## Data path

The tile consumes the same broadcast `DataHub.frame_received` signal as the
other GUI visualizations:

```text
DeviceWorker -> StreamHub -> QtDataBridge -> DataHub
                                      -> sensor_plot_readout
                                      -> live_plot
                                      -> sensor_readout
```

It does not remove data from any other consumer. The same sensor can therefore
be plotted, shown as text, recorded, and consumed by future automation logic at
the same time.

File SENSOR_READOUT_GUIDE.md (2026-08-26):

# Generic Sensor Readout Panels

The `sensor_readout` dashboard panel is the generalized replacement for the
old temperature-only monitor.  It displays the most recent numeric value of any
enabled sensors defined in `config/sensors.yaml`.

A readout panel is a GUI consumer only:

```text
serial devices -> DeviceManager -> StreamHub -> QtDataBridge -> DataHub
                                                        |
                                                        +-> sensor_readout
```

It never opens a serial port and it does not create its own data thread.  This
means the same sensor can safely appear in a plot, the recorder, an automation
subscriber, and several readout panels at the same time.

## Basic dashboard YAML

```yaml
- id: controller_conditions
  type: sensor_readout
  title: Controller Conditions
  row: 2
  column: 0
  row_span: 1
  column_span: 1
  removable: true
  config:
    channels:
      - controller.temperature
      - controller.pressure_supply
      - controller.pressure_output
    columns: 2
    default_decimals: 1
    value_font_size: 24
    show_units: true
    show_source: false
    stale_after_s: 5.0
```

`channels` may mix physical quantities and source devices.  Their order in YAML
is the order used to build the cards.

## Multiple independent panels

Use a different `id` and grid position for each panel:

```yaml
- id: chamber_conditions
  type: sensor_readout
  title: Chamber
  row: 2
  column: 0
  config:
    channels:
      - controller.temperature
      - controller.pressure_output
    columns: 2

- id: room_conditions
  type: sensor_readout
  title: Room
  row: 2
  column: 1
  config:
    channels:
      - environment.temperature
      - environment.humidity
    columns: 2
```

The dashboard automatically expands when a new tile is placed in a new row or
column.  The Add Dashboard Panel dialog now defaults to the first free grid cell
instead of `(0, 0)`.

## Per-sensor display overrides

A tile may override presentation for individual sensors without changing the
project-wide `SensorDefinition`:

```yaml
config:
  channels:
    - controller.temperature
    - controller.pressure_supply
  default_decimals: 2
  display:
    controller.temperature:
      label: Board Temp
      decimals: 1
    controller.pressure_supply:
      label: Supply Pressure
      format: .4g
      font_size: 28
```

Supported per-channel keys are:

- `label`: tile-local display label
- `unit`: tile-local unit text
- `decimals`: fixed decimal places
- `format`: Python numeric format specification such as `.3f` or `.4g`
- `font_size`: value font size for that channel

If `format` is present it takes precedence over `decimals`.

A sensor may also set project-wide defaults in `sensors.yaml` metadata:

```yaml
controller.temperature:
  label: Controller Temperature
  source_device: controller
  source_channel: controller_temperature
  unit: °C
  enabled: true
  metadata:
    quantity: temperature
    display_decimals: 1
    display_format: .2f
```

Tile-local `display` overrides take precedence over sensor metadata.

## Legacy temperature monitor

Existing YAML using:

```yaml
type: temperature_monitor
```

continues to load.  `TemperatureMonitorTile` now subclasses the generic
`SensorReadoutTile`.  New panels should use `type: sensor_readout`.

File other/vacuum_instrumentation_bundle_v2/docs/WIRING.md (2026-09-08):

# Wiring reference — v2 native-ADC baseline

## 1. Leybold GRAPHIX — direct RS-232
Use the rear **RS232/RS485** DB9 and a **straight-through, shielded** serial extension plus a real USB-to-RS232 adapter.

GRAPHIX DB9:
- pin 2 = TxD (RS-232)
- pin 3 = RxD (RS-232)
- pin 5 = GND

Typical/default communication is 38400 baud, 8 data bits, no parity, 1 stop bit, no hardware handshake. Do **not** use a TTL-UART cable and do **not** use a null-modem cable/adapter.

## 2. Native Adalogger four-channel 0-10 V front end
The Feather's ADC pins are 3.3 V-domain inputs, so every 0-10 V instrument channel needs attenuation.

Per populated channel:

```
Instrument signal ---- 30.1 kΩ 0.1% ----+---- Feather A0/A1/A2/A3
                                         |
                                       10.0 kΩ 0.1%
                                         |
Instrument signal ground ----------------+---- Feather GND
                                         |
                                        100 nF
                                         |
                                        GND
```

Divider gain from ADC voltage back to instrument voltage:

`(30.1k + 10.0k) / 10.0k = 4.01`

Important points:
- 10.0 V instrument output -> ~2.494 V at the Feather ADC.
- ~13.23 V instrument output would reach ~3.30 V at the ADC.
- This gives useful headroom around the GP475's approximately 10 V fault indication.
- Divider input resistance is ~40.1 kΩ, which is above the PDR-D-1's specified 10 kΩ minimum load.
- 100 nF provides simple low-pass/noise filtering together with the divider impedance.

Populate CH0/A0 and CH1/A1 for the current system; CH2/A2 and CH3/A3 are optional spares.

### Calibration
The RP2040 ADC is sufficient for these slow gauge outputs, but the 3.3 V reference/supply and ADC transfer function are not laboratory-grade references. For better absolute accuracy, apply two known input voltages (ideally spanning the normal range), measure them with a good DMM, and set per-channel gain/offset constants in firmware.

Firmware averaging reduces random noise. It does not eliminate deterministic ADC nonlinearity.

## 3. Granville-Phillips 475001-00-T
Use the rear analog-output 1/8-inch (3.5 mm) miniature phone jack. Verify the connector wiring against the exact unit/manual before energizing the DAQ connection.

Recommended configuration:
- output mode: **1 V/decade, 0-7 V**
- programmed analog-output offset: preferably 0 V

Reference assignment:
- GP475 analog signal -> divider -> Feather A0
- GP475 analog return -> Feather GND

The GP475 can indicate a gauge fault/disconnection with an output near 10 V; the native-ADC divider is designed to accommodate this without approaching the Feather's 3.3 V input ceiling.

## 4. MKS PDR-D-1
Use the rear terminal strip:
- **DC OUT** -> divider -> Feather A1
- **S GND** -> Feather GND

Do not substitute P GND for S GND unless the exact wiring/manual requires it. The PDR-D-1 DC OUT is nominally 0-10 V and requires a load impedance of 10 kΩ or greater; the ~40.1 kΩ divider satisfies this.

Pressure conversion requires the full-scale range of the attached Baratron.

## 5. Grounding
This reference DAQ is **not isolated**. Once connected, instrument signal grounds are tied through the Feather and laptop USB ground. Before connecting multiple line-powered instruments, measure for unexpected DC/AC potential between their signal grounds. If ground-loop current/noise appears, use isolation or a commercial isolated DAQ rather than trying to solve it only in software.

## Suggested channel assignment
- A0 / CH0 = GP475 analog output
- A1 / CH1 = PDR-D-1 DC OUT
- A2 / CH2 = spare
- A3 / CH3 = spare

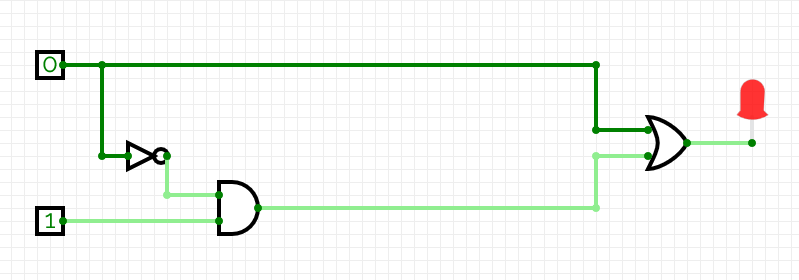
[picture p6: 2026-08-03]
other/logic_gates_manual_override_coldex.png

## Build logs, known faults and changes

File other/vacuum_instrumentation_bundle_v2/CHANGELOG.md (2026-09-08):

# Changelog

## v2
- Changed recommended analog acquisition from ADS1115 to the Feather RP2040 Adalogger's onboard ADCs.
- Added native-ADC Arduino and CircuitPython firmware while preserving the existing JSON USB protocol.
- Changed analog divider to 30.1 kΩ / 10.0 kΩ, giving a 4.01 reconstruction gain and ~2.494 V ADC input at 10 V instrument output.
- Retained ADS1115 implementation as an optional upgrade path.
- Reworked BOM structure by shared analog DAQ, GP475, PDR-D-1, GRAPHIX RS-232, and optional upgrades.
- Added direct purchase links and current approximate prices.

## v1
- Initial GRAPHIX serial, analog DAQ, conversion helpers, wiring notes, and BOM.

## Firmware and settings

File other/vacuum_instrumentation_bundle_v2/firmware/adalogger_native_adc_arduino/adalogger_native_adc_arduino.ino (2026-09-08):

/*
  Adafruit Feather RP2040 Adalogger - native ADC 0-10 V DAQ example

  Four analog channels use the RP2040's onboard 12-bit ADCs (A0-A3).
  Each input MUST be scaled before it reaches the Feather. The reference
  front end is:

      instrument -- 30.1k --+-- AIN (A0..A3)
                             |
                           10.0k
                             |
                            GND

      100 nF from AIN to GND

  Divider gain (instrument volts / ADC volts) = 4.01.
  Thus 10 V -> ~2.494 V at the RP2040 ADC and 13.23 V -> ~3.3 V.

  USB serial protocol is intentionally compatible with the ADS1115 example:
      PING
      INFO
      READ
      START
      STOP
      RATE <Hz>   (0.2 to 50 Hz)

  Streamed samples are newline-delimited JSON:
      {"type":"sample","t_us":123456,"volts":[4.0001,5.0002,0.0,0.0]}

  IMPORTANT:
  - ADC_REFERENCE_V is nominal. For better absolute accuracy, measure the
    board's 3.3 V rail/reference behavior and calibrate each channel against
    a trustworthy DMM using CAL_SCALE and CAL_OFFSET_V.
  - Averaging reduces random noise but does not remove RP2040 ADC INL/DNL.
  - This is a non-isolated DAQ. Check ground potentials before connecting
    multiple line-powered instruments.
*/

#include <Arduino.h>

static const uint8_t ADC_PINS[4] = {A0, A1, A2, A3};

// Reference/front-end constants.
static constexpr float ADC_REFERENCE_V = 3.3000f;
static constexpr float ADC_MAX_CODE = 4095.0f;
static constexpr float R_TOP_OHM = 30100.0f;
static constexpr float R_BOTTOM_OHM = 10000.0f;
static constexpr float DIVIDER_GAIN = (R_TOP_OHM + R_BOTTOM_OHM) / R_BOTTOM_OHM; // 4.01

// Channel calibration. After comparing against a DMM, use:
// V_corrected = V_uncalibrated * CAL_SCALE[ch] + CAL_OFFSET_V[ch]
static float CAL_SCALE[4] = {1.0f, 1.0f, 1.0f, 1.0f};
static float CAL_OFFSET_V[4] = {0.0f, 0.0f, 0.0f, 0.0f};

static uint16_t averagesPerReading = 64;
static bool streaming = false;
static float sampleRateHz = 10.0f;
static uint32_t nextSampleUs = 0;

String lineBuffer;

float readInstrumentVoltage(uint8_t channel) {
  uint32_t sum = 0;
  for (uint16_t i = 0; i < averagesPerReading; ++i) {
    sum += analogRead(ADC_PINS[channel]);
  }

  const float avgCode = static_cast<float>(sum) / averagesPerReading;
  const float adcVolts = (avgCode / ADC_MAX_CODE) * ADC_REFERENCE_V;
  const float inputVolts = adcVolts * DIVIDER_GAIN;
  return inputVolts * CAL_SCALE[channel] + CAL_OFFSET_V[channel];
}

void emitSample() {
  const uint32_t t = micros();
  float v[4];
  for (uint8_t ch = 0; ch < 4; ++ch) {
    v[ch] = readInstrumentVoltage(ch);
  }

  Serial.print(F("{\"type\":\"sample\",\"t_us\":"));
  Serial.print(t);
  Serial.print(F(",\"volts\":["));
  for (uint8_t ch = 0; ch < 4; ++ch) {
    if (ch) Serial.print(',');
    Serial.print(v[ch], 6);
  }
  Serial.println(F("]}"));
}

void emitInfo() {
  Serial.print(F("{\"type\":\"info\",\"device\":\"adalogger_native_adc\",\"adc\":\"rp2040_12bit\",\"channels\":4,"));
  Serial.print(F("\"divider_gain\":"));
  Serial.print(DIVIDER_GAIN, 6);
  Serial.print(F(",\"adc_reference_v\":"));
  Serial.print(ADC_REFERENCE_V, 4);
  Serial.print(F(",\"averages\":"));
  Serial.print(averagesPerReading);
  Serial.println(F("}"));
}

void handleCommand(String cmd) {
  cmd.trim();
  cmd.toUpperCase();

  if (cmd == "PING") {
    Serial.println(F("{\"type\":\"ack\",\"command\":\"PING\",\"value\":\"PONG\"}"));
  } else if (cmd == "INFO") {
    emitInfo();
  } else if (cmd == "READ") {
    emitSample();
  } else if (cmd == "START") {
    streaming = true;
    nextSampleUs = micros();
    Serial.println(F("{\"type\":\"ack\",\"command\":\"START\"}"));
  } else if (cmd == "STOP") {
    streaming = false;
    Serial.println(F("{\"type\":\"ack\",\"command\":\"STOP\"}"));
  } else if (cmd.startsWith("RATE ")) {
    const float requested = cmd.substring(5).toFloat();
    if (requested >= 0.2f && requested <= 50.0f) {
      sampleRateHz = requested;
      Serial.print(F("{\"type\":\"ack\",\"command\":\"RATE\",\"hz\":"));
      Serial.print(sampleRateHz, 3);
      Serial.println(F("}"));
    } else {
      Serial.println(F("{\"type\":\"error\",\"message\":\"RATE must be 0.2..50 Hz\"}"));
    }
  } else {
    Serial.println(F("{\"type\":\"error\",\"message\":\"unknown command\"}"));
  }
}

void setup() {
  Serial.begin(115200);
  analogReadResolution(12);
  for (uint8_t ch = 0; ch < 4; ++ch) pinMode(ADC_PINS[ch], INPUT);

  // USB CDC does not actually depend on this baud value. Do not block forever
  // waiting for a host so the board can start even when the laptop is absent.
  const uint32_t waitStart = millis();
  while (!Serial && (millis() - waitStart < 2500)) delay(10);
  emitInfo();
}

void loop() {
  while (Serial.available()) {
    const char c = static_cast<char>(Serial.read());
    if (c == '\n' || c == '\r') {
      if (lineBuffer.length()) {
        handleCommand(lineBuffer);
        lineBuffer = "";
      }
    } else if (lineBuffer.length() < 120) {
      lineBuffer += c;
    }
  }

  if (streaming) {
    const uint32_t now = micros();
    if (static_cast<int32_t>(now - nextSampleUs) >= 0) {
      emitSample();
      const uint32_t periodUs = static_cast<uint32_t>(1000000.0f / sampleRateHz);
      nextSampleUs += periodUs;
      // Recover gracefully after a long stall.
      if (static_cast<int32_t>(now - nextSampleUs) > static_cast<int32_t>(periodUs * 2U)) {
        nextSampleUs = now + periodUs;
      }
    }
  }
}

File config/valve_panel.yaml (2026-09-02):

panel:
  title: Scalable Pneumatic Valve Panel Editor
  design_width: 900.0
  design_height: 550.0
  default_element_size:
  - 42.712
  - 42.712
  background_color: '#f8f8f8'
valve_types:
  solenoid_2_way:
    display_name: 2-Way Solenoid Valve
    shape: circle
    description: Simple relay-driven on/off valve.
  solenoid_3_way:
    display_name: 3-Way Solenoid Valve
    shape: diamond
    description: Directional or routing valve.
  selector_valve:
    display_name: Selector / Routing Valve
    shape: hexagon
    description: Manifold selector or routing valve.
  pneumatic_actuator:
    display_name: Pneumatic Actuator
    shape: rounded_rect
    description: Cylinder, bladder, gripper, or other actuator.
  pump_or_source:
    display_name: Pump / Pressure Source
    shape: triangle
    description: Pump, vacuum source, or pressure-source relay.
elements:
- id: valve_01
  label: '1'
  element_type: solenoid_2_way
  center:
  - 300.0
  - 275.0
  size:
  - 42.712
  - 42.712
  rotation: 90.0
  initially_active: false
  enabled: true
  locked: false
  metadata:
    legacy_arduino_pin: 2
    legacy_button: Button 1
  actuator_id: valve_01
- id: valve_02
  label: '2'
  element_type: solenoid_2_way
  center:
  - 375.0
  - 275.0
  size:
  - 42.712
  - 42.712
  rotation: 90.0
  initially_active: false
  enabled: true
  locked: false
  metadata:
    legacy_arduino_pin: 3
    legacy_button: Button 2
  actuator_id: valve_02
- id: valve_03
  label: '3'
  element_type: solenoid_2_way
  center:
  - 450.0
  - 275.0
  size:
  - 42.712
  - 42.712
  rotation: 90.0
  initially_active: false
  enabled: true
  locked: false
  metadata:
    legacy_arduino_pin: 4
    legacy_button: Button 3
  actuator_id: valve_03
- id: valve_04
  label: '4'
  element_type: solenoid_2_way
  center:
  - 525.0
  - 275.0
  size:
  - 42.712
  - 42.712
  rotation: 90.0
  initially_active: false
  enabled: true
  locked: false
  metadata:
    legacy_arduino_pin: 5
    legacy_button: Button 4
  actuator_id: valve_04
- id: valve_05
  label: '5'
  element_type: solenoid_2_way
  center:
  - 600.0
  - 275.0
  size:
  - 42.712
  - 42.712
  rotation: 90.0
  initially_active: false
  enabled: true
  locked: false
  metadata:
    legacy_arduino_pin: 6
    legacy_button: Button 5
  actuator_id: valve_05
- id: element_22
  label: '22'
  element_type: solenoid_2_way
  center:
  - 675.0
  - 275.0
  size:
  - 42.7
  - 42.7
  rotation: 90.0
  initially_active: false
  enabled: true
  locked: false
  actuator_id: element_22
pipes:
- id: pipe_002
  start:
  - 300.0
  - 275.0
  end:
  - 300.0
  - 175.0
  thickness: 18.0
- id: pipe_003
  start:
  - 375.0
  - 275.0
  end:
  - 375.0
  - 175.0
  thickness: 18.0
- id: pipe_001
  start:
  - 450.0
  - 275.0
  end:
  - 450.0
  - 175.0
  thickness: 18.0
- id: pipe_004
  start:
  - 525.0
  - 175.0
  end:
  - 525.0
  - 275.0
  thickness: 18.0
- id: pipe_005
  start:
  - 600.0
  - 175.0
  end:
  - 600.0
  - 275.0
  thickness: 18.0
- id: pipe_006
  start:
  - 300.0
  - 275.0
  end:
  - 300.0
  - 375.0
  thickness: 18.0
- id: pipe_007
  start:
  - 375.0
  - 275.0
  end:
  - 375.0
  - 375.0
  thickness: 18.0
- id: pipe_008
  start:
  - 450.0
  - 275.0
  end:
  - 450.0
  - 375.0
  thickness: 18.0
- id: pipe_009
  start:
  - 525.0
  - 275.0
  end:
  - 525.0
  - 375.0
  thickness: 18.0
- id: pipe_010
  start:
  - 600.0
  - 275.0
  end:
  - 600.0
  - 375.0
  thickness: 18.0
- id: pipe_011
  start:
  - 675.0
  - 275.0
  end:
  - 675.0
  - 175.0
  thickness: 18.0
- id: pipe_012
  start:
  - 675.0
  - 275.0
  end:
  - 675.0
  - 375.0
  thickness: 18.0

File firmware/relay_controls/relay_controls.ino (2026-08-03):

// State machine states (may not be useful but here for now)
enum {
  INIT,
  IDLE,
  ACTIVE,
  ERROR
};
int state = INIT;  // Start in init state

// Serial Comms
const int serial_clock = 9600;  // baud rate
const byte numChars = 32;         // Max serial message length
char receivedChars[numChars];     // Array to store serial msgs
bool newData = false;             // flag to indicate the prescence of a new message

// Command return messages
#define FAILURE             0x00
#define SUCCESS             0x01
#define RELAY_DELAY_FAILURE 0x02
#define INVALID_ADDR        0x03
#define INVALID_CMD         0x04
#define GATE_STATE_WARNING  0x05

// Define pins for associated relays
const int relay_pins[3][8] = {
  {22, 23, 24, 25, 26, 27, 28, 29}, // Relay module 1
  {32, 33, 34, 35, 36, 37, 38, 39}, // Relay module 2
  {42, 43, 44, 45, 46, 47, 48, 49}  // Relay module 3
  };

// Relay state management
const byte start_state = HIGH; // HIGH or LOW
const int num_relays = 3;
const int num_switches = 8;
const int num_relay_switches = num_relays * num_switches;
const float relay_switch_delay = 100.0;              // (ms), minimum switching delay
unsigned long relay_switching_timers[3][8] = {0.0};  // (ms), timers in ms to prevent rapid relay switching
enum { OPEN,
       CLOSED };    // ---------------- change to<1 match solenoid state and corresponding relay default (open or closed)
int gate_state[3][8];  // This assumes all open (which means nothing physically yet)


void setup() 
{
  // Setup Serial
  Serial.begin(serial_clock);
  delay(50);
  // Serial.println("Serial started");
  // clearInputBuffer();
  // delay(1000);

  // Cycle through all pins connected to relays and set them to OUTPUT pins
  for (int relay_module = 0; relay_module < 3; relay_module++) {
    for (int relay_channel = 0; relay_channel < 8; relay_channel++) {
      pinMode(relay_pins[relay_module][relay_channel], OUTPUT);
      digitalWrite(relay_pins[relay_module][relay_channel], start_state);
    }
  }
  // Serial.println("Setup Complete");
}

void loop() 
{
  recvWithStartEndMarker();
  
  if (newData) {
  Serial.println("New data: " + String(newData));
    bool action_completion = parseCommands();
    if (action_completion) {
      Serial.println(SUCCESS);
    } else {
      Serial.println(FAILURE);
    }
  }
}


bool changeRelaySwitchState(const int relay, const int relay_switch, int state) {
    // If cannot switch return
    if (!canSwitch(relay, relay_switch)) {
      return false;
    }
    int pin = relay_pins[relay][relay_switch];
    if (state == 0) { digitalWrite(pin, HIGH); }      // Close the gate (Depends on default setting)
    else if (state == 1) { digitalWrite(pin, LOW); }  // Open the gate
    else { return false; }                            // Invalid state switching request
    relay_switching_timers[relay][relay_switch] = millis();  // Reset delay timer for switch
    return true;
}

bool canSwitch(const int relay, const int relay_switch)
// Check if switch is still on timer delay
{
  float switch_delta = millis() - relay_switching_timers[relay][relay_switch];
  if (switch_delta > relay_switch_delay) {
    return true;  // Switch is off delay
  } else {
    return false;  // Still on delay
  }
}

// Function to accept and retain serial input
void recvWithStartEndMarker() 
{
  static boolean recvInProgress = false;
  static byte ndx = 0;
  char startMarker = '<';
  char endMarker = '>';
  char rc;
  
  // Loop through the serial message until we receive an end character.
  while (Serial.available() > 0 && newData == false) {
    // Read one byte.
    rc = Serial.read();
    // If we're currently reading data:
    if (recvInProgress == true) {
      // If we haven't received an "end" char,
      if (rc != endMarker) {
        // Add the char to our data array and increase the index.
        receivedChars[ndx] = rc;
        ndx++;
        // If we've received more than the expected 32 bits, no we haven't.
        if (ndx >= numChars) {
          ndx = numChars - 1;
        }
      }
      // Otherwise, we've received an "end" char.
      else {
        // Terminate the string
        receivedChars[ndx] = '\0';
        // Reset the flags for the next command
        recvInProgress = false;
        ndx = 0;
        newData = true;
      }
    }
    // Otherwise, check if the character is our "start" char. If so, we should start reading data...
    else if (rc == startMarker) {
      // So set that flag appropriately.
      recvInProgress = true;
    }
  }
}

// Breakdown msg and execute commands
bool parseCommands() 
{
  if (newData) {
    // -------- Break down msg into parts --------
    char* strtokIndx;

    strtokIndx = strtok(receivedChars, ",");  // Get msb, used to pick item to act on (ex: select valve number)
    if (strtokIndx == NULL) {
    newData = false;
    return false;
    }
    int msb = atoi(strtokIndx);

    strtokIndx = strtok(NULL, ",");  // Get lb, used to decide action on item (ex: open or close valve)
    if (strtokIndx == NULL) {
    newData = false;
    return false;
    }
    int lsb = atoi(strtokIndx);

    // -------- Choose action to take from msg --------
    bool action_success = false;
    // int cmd_return_code[2];
    
    // Acting on a relay switch
    if (msb < num_relay_switches) {
      // Get relay number and switch number from msb
      int relay = (int)floor( (float)msb / ((float)num_switches) );
      int relay_switch = msb % num_switches;
      Serial.print(relay); Serial.print(", "); Serial.println(relay_switch);
      action_success = changeRelaySwitchState(relay, relay_switch, lsb);
    } 
    else {
      action_success = false;
    }
    newData = false;
    return action_success;
  }
}

void clearInputBuffer() 
{
  while (Serial.available() > 0) {
    Serial.read();
  }
}

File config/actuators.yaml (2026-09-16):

schema_version: 1
actuators:
  valve_01:
    label: '1'
    kind: solenoid_2_way
    device_id: controller
    relay_number: 1
    enabled: true
    default_active: false
  valve_02:
    label: '2'
    kind: solenoid_2_way
    device_id: controller
    relay_number: 2
    enabled: true
    default_active: false
  valve_03:
    label: '3'
    kind: solenoid_2_way
    device_id: controller
    relay_number: 3
    enabled: true
    default_active: false
  valve_04:
    label: '4'
    kind: solenoid_2_way
    device_id: controller
    relay_number: 4
    enabled: true
    default_active: false
  valve_05:
    label: '5'
    kind: solenoid_2_way
    device_id: controller
    relay_number: 5
    enabled: true
    default_active: false
  element_22:
    label: '22'
    kind: solenoid_2_way
    device_id: controller
    relay_number: 22
    enabled: true
    default_active: false
  crusher_1:
    label: Crusher 1
    kind: crusher_solenoid
    device_id: controller
    relay_number: null
    enabled: false
    default_active: true
    metadata:
      powered_state: raised_retracted
      unpowered_state: lowered_extended
  crusher_2:
    label: Crusher 2
    kind: crusher_solenoid
    device_id: controller
    relay_number: null
    enabled: false
    default_active: true
    metadata:
      powered_state: raised_retracted
      unpowered_state: lowered_extended
  crusher_3:
    label: Crusher 3
    kind: crusher_solenoid
    device_id: controller
    relay_number: null
    enabled: false
    default_active: true
    metadata:
      powered_state: raised_retracted
      unpowered_state: lowered_extended
  crusher_4:
    label: Crusher 4
    kind: crusher_solenoid
    device_id: controller
    relay_number: null
    enabled: false
    default_active: true
    metadata:
      powered_state: raised_retracted
      unpowered_state: lowered_extended

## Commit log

2026-06-12 starting relay test code
2026-06-12 safe switching delays
2026-06-13 Update relay8.ino
    Can read serial monitor inputs and execute commands
2026-06-13 Update relay8.ino
    start implementing more complex cmd completion codes. Starting to add serial return messages
2026-06-13 Create arduino_interface_v2.py
    start working on updated, more flexible serial interface meant to be used with not just arduino but serial devices in general. Might end up being only useful for arduino depending on the peculiaritie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
2026-06-13 connecting successfully to arduino
    Writing code now to get bi-directional communications going
2026-06-19 firmware change for multiple relay arrays
2026-06-20 make a mounting plate for hardware
    [arduino_mega_standoffs.0001.ipt, arduino_mega_standoffs.ipt, base_plate.0001.ipt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]
2026-06-20 create mounting hardware
    microcontroller and relay module mounting
    [arduino_due_standoffs.ipt, base_plate.0001.ipt, base_plate.0005.ipt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]
2026-06-21 standoff stls for test prints
    [arduino_mega_standoffs.stl, relay_module_standoffs_angled.stl]
2026-06-23 mounting hardware parts
    [base_plate.0005.ipt, base_plate.0006.ipt, base_plate.ipt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]
2026-06-23 mounting hardware revisions
    [base_plate.0006.ipt, base_plate.0007.ipt, base_plate.ipt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]
2026-07-03 hardware mounting test prints
    [arduino_mega_standoffs.0001.ipt, arduino_mega_standoffs.0003.ipt, arduino_mega_standoffs.ipt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]
2026-07-03 more mounting hardware
    [arduino_mega_standoffs_test.0002.ipt, arduino_mega_standoffs_test.0003.ipt, arduino_mega_standoffs_test.ipt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]
2026-07-04 adjusted dimension on db-25 mount
    [db-25_standoffs.0003.ipt, db-25_standoffs.0004.ipt, db-25_standoffs.ipt]
2026-07-04 more mounting
    [arduino_mega_standoffs_retention-clips.0004.ipt, arduino_mega_standoffs_retention-clips.ipt, arduino_mega_standoffs_retention-clips_v1.stl]
2026-07-04 db-25 standoff test
    [db-25_standoffs_test.0002.ipt, db-25_standoffs_test.0003.ipt, db-25_standoffs_test.ipt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]
2026-07-04 test prints and gcode
    [arduino_mega_standoffs_retention-clips_single.0001.ipt, arduino_mega_standoffs_retention-clips_single.ipt, arduino_mega_standoffs_retention-clips_single.stl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]
2026-07-04 all mounts ready for printing
    [47065T418_T-Slotted Framing.ipt, arduino_due_standoffs.ipt, arduino_mega_standoffs.ipt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]
2026-07-06 proto-board mounting plate
    [proto-board_standoffs_plate.0002.ipt, proto-board_standoffs_plate.0003.ipt, proto-board_standoffs_plate.ipt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]
2026-07-07 recover deleted relay control firmware
2026-07-20 file restructure, start barebones refactor
    [dataFull.csv, metadata.csv]
2026-08-25 start making temperature tile
2026-08-26 Text sensor value display tiles
2026-09-02 new tiles, central actuator registry
2026-09-08 instrumentation stuff and boms
    [BOM.csv, BOM.xlsx]
2026-09-08 test layouts and test parts
    [BOM.csv, acrylic_base.0003.ipt, acrylic_base.ipt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]
2026-09-16 full assembly progress
    [1ft_T-Slotted Framing.ipt, 30mm_1ft_T-Slotted Framing.ipt, 30mm_4ft_T-Slotted Framing.ipt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]
2026-09-16 assembly updates
    [0.257in_innerD_Moisture-Resistant Cushioning Washer.0001.ipt, 0.257in_innerD_Moisture-Resistant Cushioning Washer.ipt, full_layout_test.0006.iam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]
2026-09-16 dummy parts for din pwr supplies
    [12V_din_voltage_regulator.ipt, 24V_din_pwr_supply.ipt, 5V_din_voltage_regulator.ipt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]
2026-09-16 din hardware mounted in assembly
    [acrylic_base.0004.ipt, acrylic_base.0005.ipt, acrylic_base.ipt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]
2026-09-16 assembly progress
    [BOM (version 1).xlsx, acrylic_cover.0003.ipt, acrylic_cover.0004.ipt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]
2026-09-16 regular assembly progress
    [acrylic_base.0005.ipt, acrylic_base.0006.ipt, acrylic_base.ipt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]
2026-09-16 regular assembly uipdate
    [adalogger_mcu_volume.ipt, full_layout_test.0026.iam, full_layout_test.0029.iam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]
2026-09-16 idk, more
    [0.125in_innerD_Moisture-Resistant Cushioning Washer.ipt, 12V_din_voltage_regulator.0001.ipt, 12V_din_voltage_regulator.ipt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]
2026-09-18 assembly and bom progress
    [12V_din_voltage_regulator.0001.ipt, 12V_din_voltage_regulator.0002.ipt, 12V_din_voltage_regulator.ipt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]
2026-09-19 final bom
    [BOM (version 1).xlsx, BOM_v1.csv, BOM_v1.xlsx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]
2026-09-27 start switch panel test bom
    [BOM_switch_panel_test_9-27-2026.xlsx]
2026-10-19 v2 layout started
    this will be the layout used for the actual final layout and generating prints and cuts
2026-10-20 usb hub clamps
2026-10-20 hole position tweaks
2026-10-20 Baseplate holes
2026-10-20 m3 mount versions
